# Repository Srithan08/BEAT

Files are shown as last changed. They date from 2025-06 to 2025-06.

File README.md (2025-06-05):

# BEAT
Biometric Evaluation and Analysis Tracker

Wearable health monitors have become the norm of modern health monitoring, allowing patients to monitor essential vitals such as heart rate, blood oxygen saturation, and body temperature in real time. Wearable health monitors allow proactive management of health, management of chronic conditions, and fitness monitoring. However, their high cost makes them inaccessible to many of the global populations, particularly in low-resource communities. To fill this chasm, this project presents the concept of a low-cost, Arduino-based wearable medical monitor capable of monitoring three vital physiological parameters: body temperature, heart rate, and SpO₂.  The prototyped medical monitor, called the Biometric Evaluation and Analysis Tracker (BEAT), consists of a pulse sensor, a MAX30102 oximeter, and a thermistor interfaced by an Arduino microcontroller. These modules were chosen based on their low cost, availability, and reliability. Modularity, scalability, and ease of hardware and software combining the device from open-source hardware and software were the device design priorities. BEAT demonstrates measurements relatively close to commercial devices, within clinically acceptable limits. This proves the technical viability of low-cost medical wearables without compromise on primary functionality. The system has widespread deployment potential: it might be employed in remote healthcare regions where traditional infrastructure does not reach, in the health settings where medical technology exists without accessibility, or to educate biomedical engineers and health scientists in classrooms. By enabling democratization of basic healthcare information by putting all files here in this github, the project enables universal health equity as well as more accessible prevention-focused care. In addition, the open-source platform promotes ongoing improvement and community innovation, thus a solution that is easily tweakable to future healthcare requirements. Ongoing development and verification could make this device a cost-effective substitute for pricey commercial monitors, allowing users around the world to take better control of their own health.

## Wiring guide:
MAX30102 Sensor:
- VCC → 3.3V on Arduino
- GND → GND
- SDA → A4
- SCL → A5

Thermistor:
- One leg → A0 on Arduino
- Other leg → 10k resistor to GND and also to 5V (voltage divider)

SSD1306 OLED Display:
- VCC → 3.3V on Arduino
- GND → GND
- SDA → A4
- SCL → A5

## Building the device:
1. Export the stl files of the arduino case to a preferred slicer and 3D print all stl file.
2. Take the arduino case and gently place the arduino within the case and put on the protective cover.
4. Use a wire stripper to remove the ruber at the end of insulated wires and then solder the wires to the pins of the MAX30102 sensor.
5. Place shrink tubing on the connections and use a heat gun to shrink it and to protect the connections.
6. Gently place the MAX30102 sensor in its case and run the wire through the top of the case and run it back to the arduino connecting it to the specific points listed in the [wiring guide](#wiring-guide).
7. Use the same method to solder insulated whires to the thermistor and run the wires through the bottom of the auduino case making sure the tip of the thermistor is the only thing poking out underneath the case.
8. Connect the thermistor wires to the arduino board as seen in the [wiring guide](#wiring-guide), soldering connections if 2 wires need to be plugged into the same port on the arduino.
9. Gently push the 3D printed pins in the arduino hole and weld the side of the pin that is not touching the arduino to the arduino case using a soldering iron to keep the arduino in place.
10. Put the SSD1306 OLED screen on the lid of the arduino case using double sided tape, ensuring a secure and tight fit.
11. Solder insulated wire to the SSD1306 and connect it back to the arduino according to the [wiring guide](#wiring-guide), soldering if nescessary.
12. Place the lid of the arduino casing on the arduino, clipping them together to ensure a tight fit..
13. Attach the battery connecter to the battery holder right next to the opening for the wire.
14. Plug in the battery connector cable into the arduino and weld the battery holder to the arduino casing using a soldering iron and slowly melting the plastic along the edge of the battery case.
15. Remove the lid of the battery connecter and place the battery within the device to turn on.
16. Connect the arduino to computer of choice and upload the arduino ide code provided here into the arduino ide and upload it into the arduino.
17. Test the device by placing the battery inside.

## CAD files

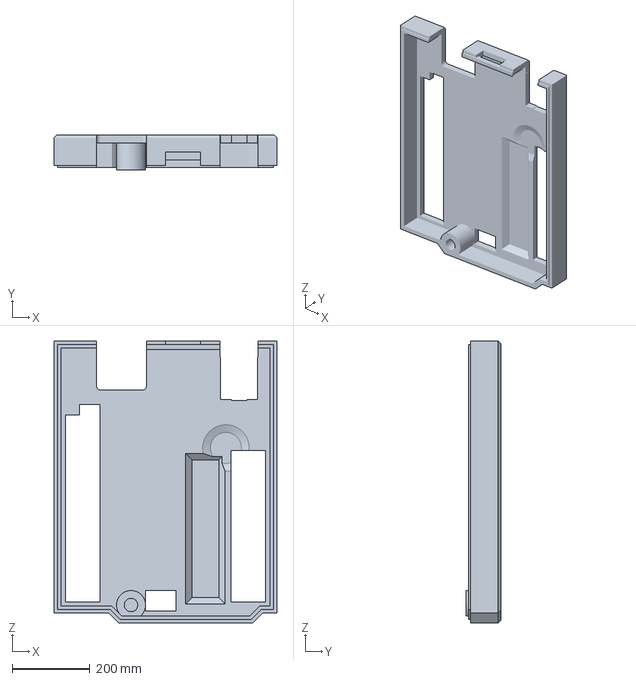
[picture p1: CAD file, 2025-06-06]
Arduino_case_top v1.3mf
575.4 x 89.1 x 727.8 mm

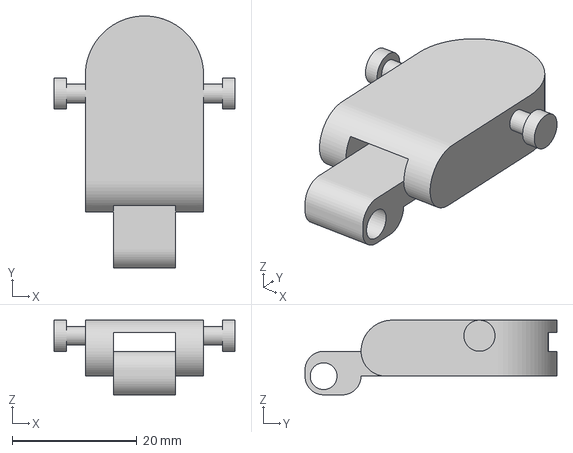
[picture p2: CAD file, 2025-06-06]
Pulse Sensor Holder Top v19.3mf
29.0 x 40.4 x 12.0 mm

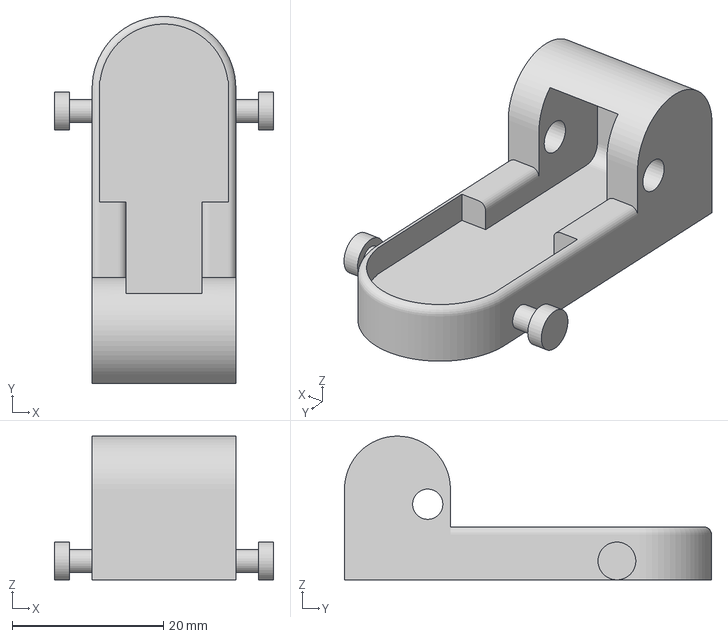
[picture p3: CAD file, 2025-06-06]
Pulse Sensor Holder Bottom v15.3mf
29.0 x 48.5 x 19.0 mm

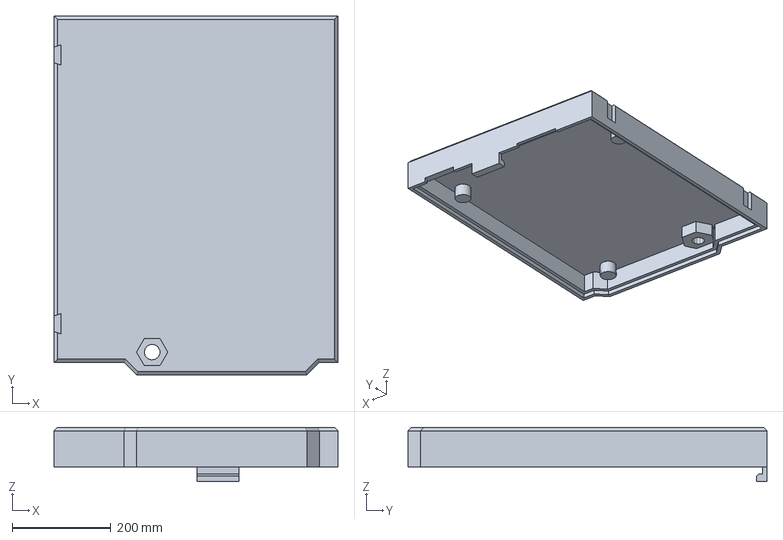
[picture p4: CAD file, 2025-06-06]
Arduino_case_bottom v1.3mf
575.4 x 727.8 x 110.0 mm

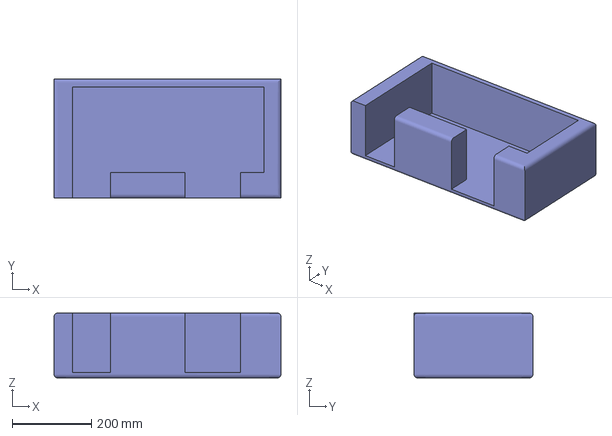
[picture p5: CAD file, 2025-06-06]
Battery Holder.3mf
573.4 x 300.8 x 164.0 mm

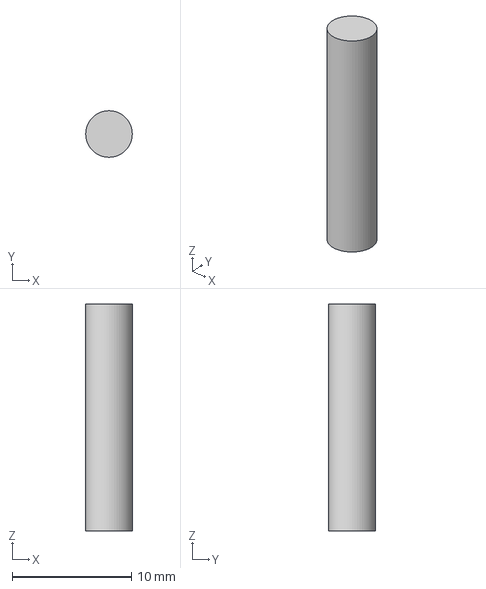
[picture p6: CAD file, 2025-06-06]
Pulse Sensor Holder Hinge Rod v2.3mf
3.90 x 3.90 x 19.0 mm

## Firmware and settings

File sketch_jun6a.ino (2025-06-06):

#include <Wire.h>
#include <Adafruit_GFX.h>
#include <Adafruit_SSD1306.h>
#include "MAX30105.h"
#include "heartRate.h"

#define SCREEN_WIDTH 128
#define SCREEN_HEIGHT 64
#define OLED_RESET -1
Adafruit_SSD1306 display(SCREEN_WIDTH, SCREEN_HEIGHT, &Wire, OLED_RESET);

MAX30105 particleSensor;

const int thermistorPin = A0;
const int SERIES_RESISTOR = 10000; // 10k resistor
const float nominalResistance = 10000;
const float nominalTemperature = 25.0;
const float bCoefficient = 3950;

// For heart rate
const byte RATE_SIZE = 4;
byte rates[RATE_SIZE];
byte rateSpot = 0;
long lastBeat = 0;
float beatsPerMinute;
int beatAvg;

void setup() {
  Serial.begin(115200);

  if (!display.begin(SSD1306_SWITCHCAPVCC, 0x3C)) {
    Serial.println(F("SSD1306 allocation failed"));
    while (true);
  }
  display.clearDisplay();
  display.setTextSize(1);
  display.setTextColor(SSD1306_WHITE);

  if (!particleSensor.begin(Wire, I2C_SPEED_STANDARD)) {
    Serial.println("MAX30102 not found. Please check wiring.");
    while (true);
  }

  particleSensor.setup(); // Configure sensor with default settings
  particleSensor.setPulseAmplitudeRed(0x0A);  // Turn Red LED to low
  particleSensor.setPulseAmplitudeIR(0x0F);   // Turn IR LED to medium
}

void loop() {
  // Heart Rate and SpO2
  long irValue = particleSensor.getIR();
  if (checkForBeat(irValue)) {
    long delta = millis() - lastBeat;
    lastBeat = millis();

    beatsPerMinute = 60 / (delta / 1000.0);

    if (beatsPerMinute < 255 && beatsPerMinute > 20) {
      rates[rateSpot++] = (byte)beatsPerMinute;
      rateSpot %= RATE_SIZE;

      beatAvg = 0;
      for (byte x = 0; x < RATE_SIZE; x++) beatAvg += rates[x];
      beatAvg /= RATE_SIZE;
    }
  }

  // Thermistor Reading
  int analogValue = analogRead(thermistorPin);
  float resistance = SERIES_RESISTOR / ((1023.0 / analogValue) - 1);
  float steinhart;
  steinhart = resistance / nominalResistance;
  steinhart = log(steinhart);
  steinhart /= bCoefficient;
  steinhart += 1.0 / (nominalTemperature + 273.15);
  steinhart = 1.0 / steinhart;
  steinhart -= 273.15;
  float temperatureF = (steinhart * 9.0) / 5.0 + 32.0;

  // Display Output
  display.clearDisplay();
  display.setCursor(0, 0);
  display.print("Heart Rate: ");
  display.print(beatAvg);
  display.println(" BPM");

  display.print("SpO2 Est.: ");
  display.print(map(irValue, 50000, 100000, 95, 100)); // crude estimate
  display.println(" %");

  display.print("Temp: ");
  display.print(temperatureF, 1);
  display.println(" F");

  display.display();
  delay(1000);
}
